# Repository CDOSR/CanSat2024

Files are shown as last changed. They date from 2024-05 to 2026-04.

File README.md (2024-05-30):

# CanSat2024

Welcome to the CanSat2024 project repository. This project is dedicated to the design, development, and deployment of a CanSat, a small satellite designed for educational purposes.

## Table of Contents
- [Introduction](#introduction)
- [Project Structure](#project-structure)
- [Getting Started](#getting-started)
- [Hardware](#hardware)
- [Software](#software)
- [Contributing](#contributing)
- [License](#license)

## Introduction
CanSat2024 is an educational initiative aimed at providing hands-on experience in satellite engineering. Participants will design, build, and launch a small satellite to achieve specific mission objectives.

## Project Structure
- `Documents/`: Documentation and guidelines for the project.
- `Hardware/`: Schematics, PCB designs, and hardware-related files.
- `Software/`: Source code for the CanSat's firmware and ground control software.

## Getting Started
### Prerequisites
- Basic understanding of electronics and programming.
- Required tools and components listed in `docs/tools_and_components.md`.

### Installation
1. Clone the repository:
    ```sh
    git clone https://github.com/CDOSR/CanSat2024.git
    ```
2. Navigate to the project directory:
    ```sh
    cd CanSat2024
    ```

## Hardware
Details about the hardware components, including sensors, microcontrollers, and power systems, can be found in the `hardware/` directory. Refer to `hardware/README.md` for more information.

## Software
The software for the CanSat includes firmware for onboard systems and software for ground control. Instructions for building and deploying the software are available in the `software/` directory. Refer to `software/README.md` for more details.

## Contributing
We welcome contributions from the community. Please read `CONTRIBUTING.md` for guidelines on how to contribute to the project.

## License
This project is licensed under the MIT License. See the `LICENSE` file for details.

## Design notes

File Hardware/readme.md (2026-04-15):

# Hardware

CAD sources for the custom PCBs designed for CanSat 2024.

## Contents

- `PCB Designs/` — Eagle `.sch` (schematic) and `.brd` (board layout) files
  for the four custom boards:
  - `Comm_board_2024_L76` — communications board with Quectel L76 GNSS
  - `Comm_board_2024_M8N` — communications board with u-blox NEO-M8N GNSS
  - `Power_board_2024` — power distribution and battery management
  - `Sensor_board_2024` — sensor aggregation (IMU, environmental, etc.)

## Component datasheets

Datasheets for the third-party components used on these boards live under
[`Documentation/Hardware/Data Sheets/`](../Documentation/Hardware/Data%20Sheets/)
— kept separate so this tree stays focused on our own CAD sources rather
than vendor reference material.

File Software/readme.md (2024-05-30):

# Software Directory

This directory contains all the software-related files for the CanSat2024 project.

## Contents
- `Main Can/`: Source code for the CanSat's onboard firmware.
- `Base Station/`: Software for the ground control station.

## Firmware
The `Main Can/` directory contains the source code that runs on the CanSat's microcontroller. This code is responsible for sensor data collection, communication, and control operations.

### Building the Firmware
To build the firmware, navigate to the `firmware/` directory and use the provided Makefile:
```sh
cd `Main Can`
make

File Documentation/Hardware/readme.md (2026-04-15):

# Hardware Documentation

Reference material for the CanSat 2024 hardware subsystems.

## Contents

- `Data Sheets/` — Manufacturer datasheets for every sensor, regulator,
  GNSS module, radio, and battery IC used on the custom boards.

## Related

The team's own hardware sources — Eagle `.sch` and `.brd` CAD files for
the four custom boards — live under [`Hardware/`](../../Hardware/) at
the repo root, so that vendor reference PDFs don't clutter the CAD tree.

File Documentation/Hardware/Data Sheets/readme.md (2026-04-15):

# Component Data Sheets

Manufacturer datasheets for the components used on the CanSat 2024
custom PCBs. One PDF per part, filename matches the manufacturer part
number.

| File | Part | Role |
|---|---|---|
| `AP2112M-3.3TRG1.pdf` | Diodes AP2112M-3.3 | 3.3 V LDO regulator |
| `BME280.pdf` | Bosch BME280 | Pressure / humidity / temperature |
| `BME688.pdf` | Bosch BME688 | Environmental + gas sensor |
| `ICM-20648.pdf` | TDK InvenSense ICM-20648 | 6-axis IMU |
| `L76-M33.pdf` | Quectel L76 | GNSS module |
| `LPS25HBTR.pdf` | ST LPS25H | MEMS pressure sensor |
| `MAX17048-MAX17049.pdf` | Maxim MAX17048/049 | Li-ion fuel gauge |
| `MCP73831T-2ACI_OT.pdf` | Microchip MCP73831 | Li-ion charger IC |
| `MCP9808-E_MS.pdf` | Microchip MCP9808 | Digital temperature sensor |
| `RN2483A-I_RM105.pdf` | Microchip RN2483 | LoRaWAN radio module |
| `VEML6075.pdf` | Vishay VEML6075 | UVA / UVB sensor |

The boards that use these parts — schematic and layout — live under
[`Hardware/PCB Designs/`](../../../Hardware/PCB%20Designs/) at the repo
root.

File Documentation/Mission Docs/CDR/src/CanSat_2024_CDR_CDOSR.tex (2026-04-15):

\documentclass[11pt]{article}
\usepackage{CDOSR_CanSat, lipsum, amssymb, array, hyperref}
\usepackage{pdflscape}
\cansatstyle
\graphicspath{{../../common/}{./}}

\title{Preliminary Design Report}
\author{Team: CDOSR (CoderDojo Space Robotics Oradea)}
\date{May 10, 2024}

\begin{document}

\cansattitle{Critical Design Report}{images/img_CDOSR.png}{images/img_CANSAT_RO.png}

\newpage

\tableofcontents
\pagestyle{plain}

\newpage
\input{section_0/section_0}
\input{section_1/section_1}
\input{section_2/section_2}
\input{section_3/section_3}
\input{section_4/section_4}
\input{section_5/section_5}
\input{section_6/section_6}
\input{section_7/section_7}

\theendnotes

\appendix
\newpage

\appendix
\addcontentsline{toc}{section}{Appendices}
\section*{Appendices}
% \section{Time Management - Gantt Chart}\label{A1}

\subsection{Task list}

\begin{enumerate}[]
    \item \textbf{Can Design and Manufacturing} - in progress
    \begin{itemize}
    \item Can design in 3D - In progress
        \begin{itemize}
            \item models for main IC
            \item power board
            \item sensor board
            \item can assembly model
        \end{itemize}
    \item Parts (Acquisition) - in progress
    \end{itemize}    
    \item \textbf{PCB Design and Manufacturing} - in progress
    \begin{itemize}
        \item PCB Design
        \begin{itemize}
            \item Power Board Design - in progress
            \item Sensor Board Design  - in progress
        \end{itemize}
        \item PCB Manufacturing
        \begin{itemize}
            \item Power Board - scheduled
            \item Sensor Board - scheduled
        \end{itemize}    
    \end{itemize}
    \item \textbf{Can Software}:
    \begin{itemize}
        \item {Mission Software}
        \begin{itemize}
            \item Sensor integration - scheduled
            \item TX/RX between devices - scheduled
            \item New mainboard software integration - scheduled
            \item Base station software - scheduled
        \end{itemize}
        \item {Post Mission Software}
        \begin{itemize}
            \item Data aggregation - scheduled
            \item Data analysis - scheduled
            \item Reporting - scheduled
        \end{itemize}
    \end{itemize}
    \item \textbf{Testing} - scheduled
    \begin{itemize}
        \item Recovery system
        \begin{itemize}
            \item Parachute - in progress, partly done
            \item Locator for Can - scheduled
        \end{itemize}
        \begin{itemize}
            \item Sensor reading - done
            \item Can-Base transmission - scheduled
            \item Base station - scheduled
        \end{itemize}
        \item Hardware
        \begin{itemize}
            \item Electronics - scheduled
            \item Batteries - scheduled
            \item Receiver Antenna - scheduled
        \end{itemize}
        \item Structure
        \begin{itemize}
            \item Crashproof - scheduled
        \end{itemize}
    \end{itemize}
\end{enumerate}

\section{Mission milestones}\label{A33}

These milestones have been designed to keep us on track and ensure that we successfully meet our project goals and deadlines.
\begin{itemize}[leftmargin=1cm, itemindent=0.25cm, noitemsep, topsep=0pt, label=$\bullet$]
    % \item Team Formation and Project Planning:
    % \begin{itemize}[label=\ding{111}, noitemsep, topsep=2pt]
    %     \item Establish team roles and responsibilities
    %     \item Recruit suitable team members for each role
    % \end{itemize}
    \item Define Project Scope and Objectives:
    \begin{itemize}[label=\ding{111}, noitemsep, topsep=0pt]
        \item Purpose of the project: to successfully detect muons and analyze the environment, light conditions
        \item Objectives to be achieved on launch day and post-launch analysis:
        \begin{multicols}{2}
        \setlength{\topsep}{0pt}
        \setlength{\partopsep}{0pt}
        \begin{itemize}[label=\ding{51}, noitemsep, topsep=0pt]
        \item Successful launch
        \item Live RF telemetry
        \item Successful parachute deployment
        \item All systems nominal (good sensor and location data)
        \item Descent rate between 7-10m/s
        \item Landing confirmation
        \item Recovery of the CanSat
        \item Generating reports
        \end{itemize}
        \end{multicols}
    \end{itemize}
    \item Develop a Detailed Project Plan and Timeline:
    \begin{itemize}[label=\ding{111}, noitemsep, topsep=0pt]
        \item Assign tasks related to social media promotion and sponsor search;
        \item Determine cooperation method (online/programs/meetings etc.)
    \end{itemize}
    \item Research and Design:
    \begin{itemize}[label=\ding{111}, noitemsep, topsep=0pt]
        \item Conduct research on required components and technologies for the mission;
        \item Design the payload's structure and select materials;
        \item Submit Preliminary Design Report;
        \item Develop a prototype and test sensors and electronics;
        \item Promote the project on social media platforms and begin searching for sponsors.
    \end{itemize}
    \item Integration and Testing:
    \begin{itemize}[label=\ding{111}, noitemsep, topsep=0pt]
        \item Integrate sensors and electronics into the payload's structure;
        \item Conduct testing and calibration;
        \item Ensure that the CanSat meets weight and size requirements;
    \end{itemize}
    \item Launch Preparation:
    \begin{itemize}[label=\ding{111}, noitemsep, topsep=0pt]
        \item Conduct pre-launch testing;
        \item Pre-launch checklist.
    \end{itemize}
    \item Primary and Secondary Missions:
    \begin{itemize}[label=\ding{111}, noitemsep, topsep=0pt]
        \item Verify that the payload met the primary mission requirements;
        \item Collect the missions data from the sensors;
        \item Conduct data analysis and report on the results;
        \item Share updates and photos of the data analysis on social media platforms.
    \end{itemize}
    \item Submit Design Reviews
    \begin{itemize}[label=\ding{111}, noitemsep, topsep=0pt]
        \item Preliminary Design Review;
        \item Critical Design Review.
    \end{itemize}
    \item Final Report and Presentation:
    \begin{itemize}[label=\ding{111}, noitemsep, topsep=0pt]
    \item Prepare a final report documenting the project's objectives, methods, and results;
    \item Develop a presentation to showcase the mission and its capabilities;
    \item Share the presentation on social media platforms to showcase the project's achievements and thank sponsors for their support.
    \end{itemize}
\end{itemize}

\newpage

% \section{Flight Simulations}\label{A33}

% % \begin{landscape}
% \begin{figure}[htbp]
%     \centering
%     \includegraphics[width=0.95\textwidth]{images/plot_rcrc.png}
%     \caption{\small{Flight simulation graphs}}
%     \label{fig:fins}
% \end{figure}
% % \end{landscape}

% \begin{table}[htbp]
% \centering
% \arrayrulecolor{DeepSkyBlue4}
% \begin{tabular}{|>{\columncolor{DeepSkyBlue4}}cc|}
% \hline
% \textbf{\color{white!50}{Velocity off rod}} & \cellcolor{LightCyan1!50}\(\SI{12.9}{\meter/\second}\)\\
% \textbf{\color{white!50}{Apogee}} & \(\SI{221}{\meter}\)\\
% \textbf{\color{white!50}\textbf{Velocity at deployment}} & \cellcolor{LightCyan1!50}\(\SI{6.03}{\meter/\second}\)\\
% \textbf{\color{white!50}\textbf{Max. velocity}} & \(\SI{62.2}{\meter/\second}\)\\
% \textbf{\color{white!50}\textbf{Max. acceleration}} & \cellcolor{LightCyan1!50}\(\SI{99.1}{\meter/\second^2}\)\\
% \textbf{\color{white!50}\textbf{Time to apogee}} & \(\SI{7.3}{\second}\)\\
% \textbf{\color{white!50}\textbf{Flight time}} & \cellcolor{LightCyan1!50}\(\SI{55.1}{\second}\)\\
% \textbf{\color{white!50}\textbf{Ground hit velocity}} & \(\SI{4.66}{\meter/\second}\)\\ 
% \hline
% \end{tabular}
% \caption{\small{Flight Simulation Information}}
% \end{table}

% \begin{wrapfigure}{l}{0.95\textheight}
%     \centering
%     \includegraphics[width=13.5cm]{images/Gantt.eps}
%     %\caption{\small{CDOSR Gantt Chart for CanSat 2023.}}
%     \label{fig:gantt}
% \end{wrapfigure}

% \begin{figure}[h]
%     \centering
%     \includegraphics[width=11.7cm]{images/Gantt.eps}
%     %\caption{\small{CDOSR Gantt Chart for CanSat 2023.}}
%     \label{fig:gantt}
% \end{figure}

% \begin{minipage}[c][\textheight]{\textwidth}
%     \vspace*{\fill}
%     \begin{figure}[h] % Use 'p' for a dedicated page for the figure
%     \centering
%     \includegraphics[width=\textwidth, keepaspectratio]{images/Gantt.eps}
%     %\caption{Your caption here}
%     \label{fig:gantt}
%     \end{figure}
%     \vspace*{\fill}
% \end{minipage}

\section{Dual parachute design (Payload's Case)}\label{A4}
\coloredbox{LightCyan1!50}{DeepSkyBlue4}{DeepSkyBlue4}{
    \begin{minipage}{0.4\textwidth}
    The smaller parachute had a diameter of 21.7 cm and a surface area of 370 cm$^{2}$, which is designed to slow down the descent speed to 9 meters per second. The design of this parachute was based on the principles of aerodynamics and is intended to withstand strong winds and turbulent weather conditions. We believe that this parachute will be instrumental in ensuring a safe and successful landing of our Payload during windy weather conditions.
    \end{minipage}
    \hfill
    \begin{minipage}{0.4\textwidth}
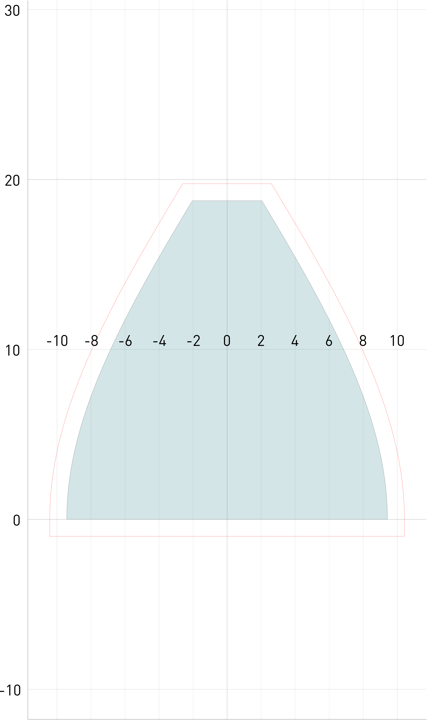
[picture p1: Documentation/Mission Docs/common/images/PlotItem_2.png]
    
    \end{minipage}
}
\coloredbox{LightCyan1!50}{DeepSkyBlue4}{DeepSkyBlue4}{
    \begin{minipage}{0.4\textwidth}
    The second parachute was designed for use during calm weather conditions and had a diameter of 32.6 cm and a surface area of 834 cm$^{2}$, which is designed to slow down the descent speed to 6 meters per second. This parachute was optimized for stable and predictable conditions and is intended to provide a gentle and controlled descent of the Payload during calm weather conditions.
    \end{minipage}
    \hfill
    \begin{minipage}{0.4\textwidth}
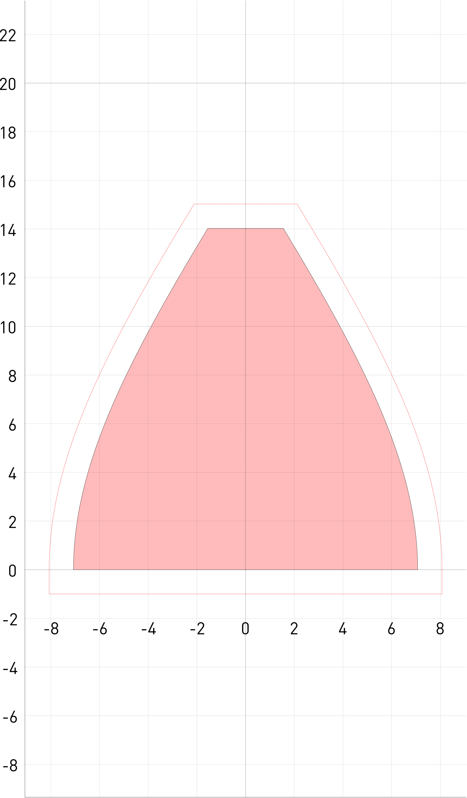
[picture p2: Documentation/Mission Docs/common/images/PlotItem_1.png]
    
    \end{minipage}
}
\newpage

\section{Payload  -  software design}\label{AE22}
\begin{figure}[htbp]
    \centering
    
    \caption{\small{Software diagram.}}
    \label{fig:codeblocks}
\end{figure}
\newpage

\section{Payload  - electrical design}\label{AE2}
% \begin{landscape}
\begin{figure}[h]
    \centering
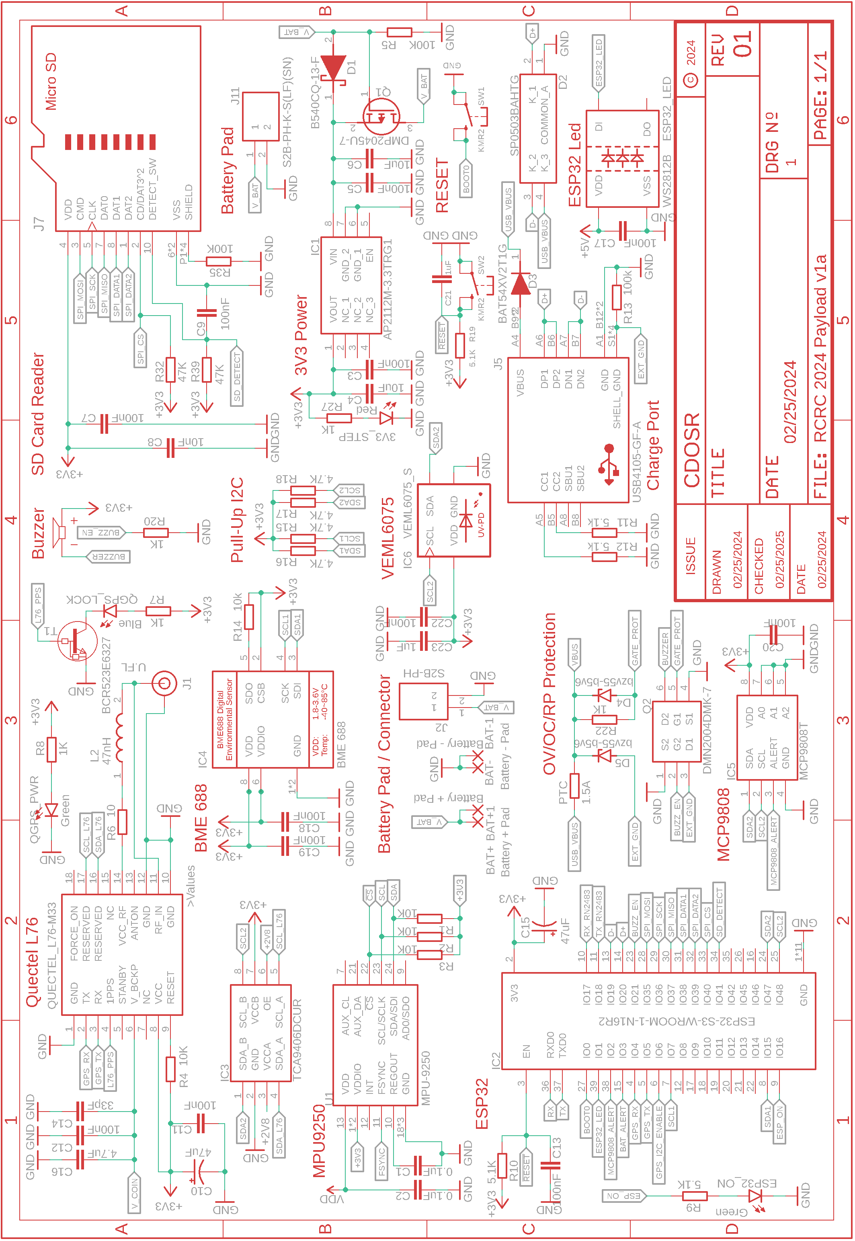
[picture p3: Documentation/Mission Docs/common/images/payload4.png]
    
    \caption{\small{CDOSR payload electrical scheme.}}
    \label{fig:gantt}
\end{figure}
% \end{landscape}
\newpage

\section{Base station - electrical design}\label{AEE2}

% \begin{landscape}
\begin{figure}[h]
    \centering
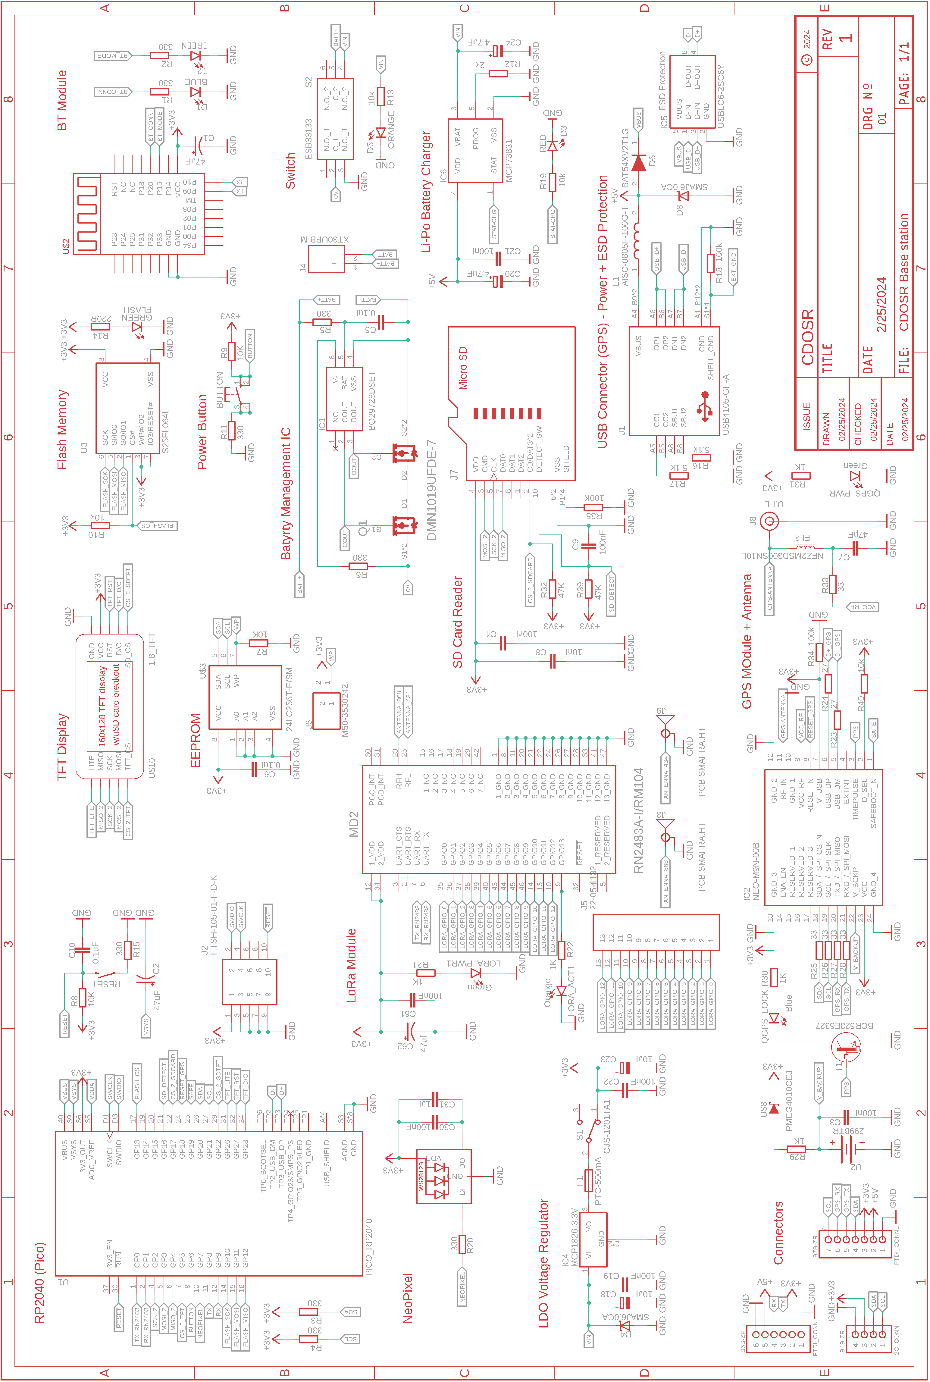
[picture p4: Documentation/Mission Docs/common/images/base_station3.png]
    
    \caption{\small{CDOSR base station electrical scheme.}}
    \label{fig:gantt}
\end{figure}
    
% \end{landscape}

\newpage

% \section{Time Management - Gantt Chart}\label{A2}

% \begin{figure}[h]
%     \centering
%     \includegraphics[width=15.5cm]{images/Gantt.eps}
%     \caption{\small{CDOSR Gantt Chart for RCRC 2024.}}
%     \label{fig:gantt}
% \end{figure}

\newpage

\section{Test plan}\label{A1}

\begin{itemize}[leftmargin=1cm, itemindent=0.25cm, noitemsep, topsep=0pt, label=\ding{51}]
\item Mission Objective Test
\begin{itemize}[label=\ding{111}, noitemsep, topsep=2pt]
\item Verify if the payload meets the competition mission requirements
\item Check that the sensors are functioning properly
\end{itemize}

\item Mechanical Test
\begin{itemize}[label=\ding{111}, noitemsep, topsep=2pt]
\item Make sure that the structure and enclosure are sturdy and can withstand launch and landing
\item Verify the parachute deployment and fixing are functional and reliable
\end{itemize}

\item Software Test
\begin{itemize}[label=\ding{111}, noitemsep, topsep=2pt]
\item Verify that the software is correctly installed and functional
\item Ensure that the software is properly processing data from the sensors and instruments
\end{itemize}

\item Communication Test
\begin{itemize}[label=\ding{111}, noitemsep, topsep=2pt]
\item Ensure that the payload can communicate with the ground station
\item Verify that telemetry data can be received and decoded correctly
\item Test the range and the reliability of the communication link
\end{itemize}

\item Power Test
\begin{itemize}[label=\ding{111}, noitemsep, topsep=2pt]
\item Verify that the power system meets the power budget and has sufficient power to operate the payload
\item Test the duration of the battery life and ensure that power consumption is minimized wherever possible
\end{itemize}

\item Integration Test
\begin{itemize}[label=\ding{111}, noitemsep, topsep=2pt]
\item Verify if all the components of the payload are properly integrated and functioning correctly
\item Test the overall functionality
\end{itemize}

\item Ground Station Test
\begin{itemize}[label=\ding{111}, noitemsep, topsep=2pt]
\item Verify that the antennas are properly installed and functional
\item Verify that the ground station software can display data from the payload
\end{itemize}

\item Battery Charging Test
\begin{itemize}[label=\ding{111}, noitemsep, topsep=2pt]
\item Test the battery charging system and verify that it can fully charge the batteries within a reasonable amount of time
\item Verify that the charging system is safe and reliable
\end{itemize}

\item Post-Mission Test
\begin{itemize}[label=\ding{111}, noitemsep, topsep=2pt]
\item Verify if the payload has returned all the required data
\item Check the data for accuracy and completeness
\item Analyze the data and compare it to the mission objectives
\end{itemize}

\end{itemize}

\section{Sensor testing}\label{A22}

\begin{itemize}[labelwidth=0cm, leftmargin=0cm, itemindent=0.7cm, noitemsep, topsep=0pt, label={}]
\item \textbf{Pressure sensor test}:
\begin{itemize}[labelwidth=2cm, leftmargin=1.9cm, label=\ding{109}, noitemsep, topsep=2pt]
\item[\faTasks] \textbf{Task}: Expose the used sensor to a pressure change and compare the results with a reference device.
\item[\faFlask] \textbf{Method}: Place the target and reference sensors in a sealed container with a known volume of air and measure the pressure change with a manometer or a barometer. The pressure can be changed by altering the volume of the container or by using a hand pump.
\item[{\faHourglass[3]}] \textbf{Estimated testing time duration}: 1-2 hours
\item[{\faCheckSquare}] \textbf{Acceptance criteria}: The test will be considered positive when both sensors show the same pressure without measuring errors.
\end{itemize}
\item \textbf{Temperature sensor test}:
\begin{itemize}[labelwidth=2cm, leftmargin=1.9cm, label=\ding{109}, noitemsep, topsep=2pt]
\item[\faTasks] \textbf{Task}:  Check whether the target device and the reference device show the same temperature within 24 hours 
\item[\faFlask] \textbf{Method}: Place both the target device and the reference device in the same location and monitor their temperature readings at regular intervals for 24 hours
\item[{\faHourglass[3]}] \textbf{Estimated testing time duration}:  24 hours
\item[{\faCheckSquare}] \textbf{Acceptance criteria}: The test will be considered positive when both sensors show the same temperature without significant deviation.
\end{itemize}
\item \textbf{Humidity sensor test}:
\begin{itemize}[labelwidth=2cm, leftmargin=1.9cm, label=\ding{109}, noitemsep, topsep=2pt]
\item[\faTasks] \textbf{Task}:  Place the target sensor and the reference device in a humidity chamber where the humidity will be increased or decreased to a specific level, and the readings will be compared.
\item[\faFlask] \textbf{Method}: The target sensor and the reference device will be placed in a humidity chamber where the humidity level will be gradually increased or decreased to a specific level. The readings from both sensors will be recorded and compared.
\item[{\faHourglass[3]}] \textbf{Estimated testing time duration}:  6 hours
\item[{\faCheckSquare}] \textbf{Acceptance criteria}: The test will be considered positive when both sensors show the same humidity level without significant deviation.
\end{itemize}
\item \textbf{UV sensor test}:
\begin{itemize}[labelwidth=2cm, leftmargin=1.9cm, label=\ding{109}, noitemsep, topsep=2pt]
\item[\faTasks] \textbf{Task}:  Expose the target sensor and the reference device to UV radiation from a UV light source and compare the readings.
\item[\faFlask] \textbf{Method}: The target sensor and the reference device will be exposed to UV radiation from a UV light source for a specific duration, and the readings will be recorded and compared.
\item[{\faHourglass[3]}] \textbf{Estimated testing time duration}:  1 hour
\item[{\faCheckSquare}] \textbf{Acceptance criteria}: The test will be considered positive when both sensors show the same UV index without significant deviation.
\end{itemize}
\item \textbf{GPS test}:
\begin{itemize}[labelwidth=2cm, leftmargin=1.9cm, label=\ding{109}, noitemsep, topsep=2pt]
\item[\faTasks] \textbf{Task}:  Test the accuracy of the GPS module by comparing the location obtained by the CanSat with the actual location.
\item[\faFlask] \textbf{Method}: The location data collected by the GPS module during this time will be recorded and compared to the actual location using a separate reference system. The reference system may be a ground-based GPS receiver or a separate device with accurate location data.
\item[{\faHourglass[3]}] \textbf{Estimated testing time duration}:  1 hour
\item[{\faCheckSquare}] \textbf{Acceptance criteria}: The test will be considered positive if the error margin is within an acceptable range.
\end{itemize}
\end{itemize}

\section{Mechanical stress testing}\label{A33333}

\begin{itemize}[labelwidth=0cm, leftmargin=0cm, itemindent=0.7cm, noitemsep, topsep=0pt, label={}]
\item \textbf{Drop resistance test}:
\begin{itemize}[labelwidth=2cm, leftmargin=1.9cm, label=\ding{109}, noitemsep, topsep=2pt]
\item[\faTasks] \textbf{Task}: Conduct a crash test to ensure the payload components can withstand the impact of a fall.
\item[\faFlask] \textbf{Method}: Prototypes will be dropped from a tower or drone to achieve the required descent speed. A fall test without a parachute will also be performed. Optionally, a 3-axis accelerometer will be added to record any G-force during the test.
\item[{\faHourglass[3]}] \textbf{Estimated testing time duration}: Estimated to be a few hours.
\item[{\faCheckSquare}] \textbf{Acceptance criteria}: All components should remain intact, and the electronics should continue to work continuously.
\end{itemize}
\item \textbf{Long-term G-force tests}:
\begin{itemize}[labelwidth=2cm, leftmargin=1.9cm, label=\ding{109}, noitemsep, topsep=2pt]
\item[\faTasks] \textbf{Task}: Simulate the G-forces that may occur during rocket transport to test the CanSat components' endurance.
\item[\faFlask] \textbf{Method}: The payload model will be placed on a carousel or string and rapidly rotated to generate the required overload due to the centrifugal force.
\item[{\faHourglass[3]}] \textbf{Estimated testing time duration}: The test will last for several hours.
\item[{\faCheckSquare}] \textbf{Acceptance criteria}: All components should remain intact, and the electronics should continue to work continuously throughout the test period.
\end{itemize}
\end{itemize}

\end{document}

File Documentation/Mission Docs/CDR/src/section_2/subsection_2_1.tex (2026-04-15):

\subsection{Mission Overview}

The CoderDojo Space Robotics project team will execute the mission by designing and constructing a CanSat that will launch and deploy from an altitude of approximately 1000 meters. During the CanSat's descent, it must maintain a speed between 5 and 10 meters per second, while it simultaneously collects and transmits key environmental data. This data will include temperature, pressure, spatial positioning, and UV radiation levels. In addition to these, the CanSat is uniquely equipped to detect muons. All of this data will be transmitted in real-time to the ground station and stored onboard. After landing, the CanSat will signal its coordinates using a buzzer, activating the recovery system.

These key elements will play an essential role in accomplishing the mission objectives. Here is a brief explanation of each element:
\begin{itemize}[leftmargin=1.27cm, itemindent=0cm, topsep=2pt, label=\faTasks]
    \item[\faThermometerQuarter] \textbf{Sensor System}: A sensor system is critical to the mission's success as it helps to measure various parameters that are important for the experiment. The sensor system can measure parameters such as temperature, pressure, inertial performance, UV, and light intensity. These measurements will provide valuable data for the post-launch data analysis.
    \coloredbox{LightCyan1!50}{DeepSkyBlue4}{DeepSkyBlue4}{
        {During the descent, the CanSat will record, store, and transmit the following data:
        \begin{multicols}{2}[\vspace{-0.6\baselineskip}]
            \begin{itemize}[noitemsep, topsep=0pt, label=\ding{111}]
                \item Humidity and air temperature
                \item Barometric pressure
                \item GPS Location
                \item Magnetic field
                \item Orientation
                \item Position in space using a gyroscope
                \item UV Index
            \end{itemize}
        \end{multicols}
        \vspace*{-0.75\baselineskip}
        }
    }
    \item[\faMicrochip] \textbf{Microcontroller}: The microcontroller is responsible for controlling the various subsystems of the CanSat. It provides a reliable and efficient way to control the CanSat's functions, making it a crucial part of the overall system.
    \item[\faBroadcastTower] \textbf{Telemetry Syste}m: The telemetry system is responsible for sending data back to the ground station. It uses GSM and RF modules to transmit data, which can be analyzed in real time by the mission team. This system helps to ensure that the mission objectives are met and that the data collected is of high quality.
    \item[ \faParachuteBox] \textbf{Recovery System}: The recovery system is essential to ensure the CanSat is safely returned to the ground. It consists of audible alarms that alert the ground station to the CanSat's location. This system will help to prevent damage to the CanSat and ensure that the data collected during the mission is preserved.
    \item[\faChartBar] \textbf{Post-Launch Data Analysis}: Post-launch data analysis is essential for interpreting the data collected during the mission. It allows the mission team to evaluate the success of the mission and determine whether the mission objectives were met. This analysis can help to inform future missions and experiments. 
\end{itemize}

%\begin{figure}[htbp]
%  \centering
%  \includesvg{img_Block_Diagram_2023.svg}
%  \caption{svg image}
%\end{figure}

\begin{figure}[htbp]
\centering
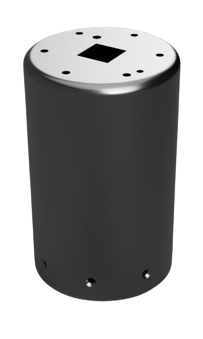
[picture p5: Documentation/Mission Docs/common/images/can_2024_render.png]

\caption{\small{Base block diagram for the CanSat and the ground station.}}
\label{fig:bloc_diagrame}
\end{figure}

Several onboard devices will make the mission possible, the key ones being:
    \begin{multicols}{2}[\vspace{-0.5\baselineskip}]
        \begin{itemize}[leftmargin=1.75cm,itemindent=0cm, noitemsep, topsep=2pt, label=\faCheck]
            \item[\faMicrochip] MicroController (ESP32 Wroom or Raspberry Py PR2040)
            % \item[\faCamera] Cameras (ESP32 With Camera Module OV2640)
            \item[ \faWifi] Data transceiver (LoRa)
            \item[\faThermometerQuarter] Humidity and temperature sensors %(BME 688, MCP 9808)
            \item[\faMapMarked] GPS (L76GNSS)
            \item[\faCompass] Navigation sensor %(LSM6DS33 gyroscope \& LIS3MDL compass )
            \item[\faBatteryHalf] High-performance batteries
            \item[\faRadiation] SiPM (Silicon photomultiplier) detector for muons
            \item[\newaltitudeicon] Altimeter %(LPS25H)
            % \item[\newgsmicon] GSM module (SIM800L)
        \end{itemize}
        \vspace*{-0.75\baselineskip}
    \end{multicols}

% \sout{The ESP32 and Arduino Nano 33 BLE Sense boards are designed to collect data from various sensors during the flight, including location, temperature, and pressure. This data is stored on an SD card for later analysis, but it is also transmitted to the base station in real-time using the LoRa protocol.

% In addition to collecting data from sensors, the boards also receive data from two GPS modules. This data is routed to the GSM communication module, which sends the GPS coordinates of the CanSat to the base station. This allows the mission team to track the CanSat's location and monitor its progress during the flight.

% Overall, the combination of the ESP32 and Arduino Nano 33 BLE Sense boards provides a reliable and efficient way to collect and transmit data during the CanSat's flight. The data collected can be analyzed after the mission to gain insights into various environmental factors and improve future missions.}

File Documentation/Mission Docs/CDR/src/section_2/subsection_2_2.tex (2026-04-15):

\subsection{Mechanical/structural design}

For the mechanical design, several factors have been considered to ensure the payload's robustness and easy maintenance:
% \begin{itemize}[leftmargin=1.75cm,itemindent=0cm, noitemsep, topsep=3pt,  label=\faCheck]
%     \item \textbf{Component protection}: The payload's structure has been designed to protect the components from any external impact or shock during the launch and landing;
%     \item \textbf{Resilient structure}: The payload's structure includes shock-absorbing systems such as foam or gel-based layers, springs, or a combination of both. These systems will help to reduce the impact force during landing, preventing damage to the payload and its components;
%     \item \textbf{Easy removal of batteries and radio transmitters}: The batteries and radio transmitters are positioned in a way that allows for easy removal in case of any malfunction or for recharging and testing purposes.;
%     \item \textbf{Easy access to components}: The payload's body has been designed to allow easy extraction of the components for maintenance or replacement in case of malfunctions
%     \item \textbf{Easy removal of batteries and radio transmitter}s: The batteries and radio transmitters are positioned in a way that allows for easy removal in case of any malfunction or for recharging and testing purposes.
% \end{itemize}

\begin{itemize}
    \item \textbf{Component Protection}: The payload's structure will be designed to protect the components from any external impact or shock during the launch and landing.
    \item \textbf{Resilient Structure}: The payload's structure will include some shock-absorbing systems to reduce the impact force during landing, thereby preventing damage to the payload and its components.
    \item \textbf{Easy Removal of Batteries and Radio Transmitters}: The batteries and radio transmitters will be positioned in a way that allows for easy removal in the event of any malfunction, or for recharging and testing purposes.
    \item \textbf{Easy Access to Components}: The design of the payload's body will facilitate easy extraction of the components for maintenance or replacement in case of malfunctions.
\end{itemize}

By considering these factors, the team aims to create a robust and reliable payload capable of withstanding the mission's harsh conditions and delivering accurate data.

The payload's structure uses a combination of Polylactic Acid (PLA) and Acrylonitrile Butadiene Styrene (ABS). These lightweight 3D printing materials provide strength, durability, and exceptional design flexibility. This composition allows the can to endure the stresses of launch and landing while maintaining an aerodynamic shape. Additionally, the can is designed with a removable bottom or top section, facilitating easy access to its internal components for maintenance and repair without dismantling the entire structure.

The design ensures durability during launch and landing, distributing and absorbing high levels of stress and force. The aerodynamic design minimizes air resistance, helping achieve maximum altitude during launch.

\begin{figure}[htbp]
\centering

\caption{\small{Payload can with parachute cords attchement places.}}
\label{figmodule_diagrame}
\end{figure}

\begin{table}[htbp]
\centering
\arrayrulecolor{DeepSkyBlue4} % set color of vertical lines
\begin{tabular}{>{\centering\arraybackslash}m{1cm}>{\centering\arraybackslash}lc}
\hline
\rowcolor{DeepSkyBlue4}
&\textbf{\color{white!50}{CanSat Characteristics (description)}} & \textbf{\color{white}{Figure (units)}} \\
\hline
%\rowcolors{2}{LightCyan!50}{}
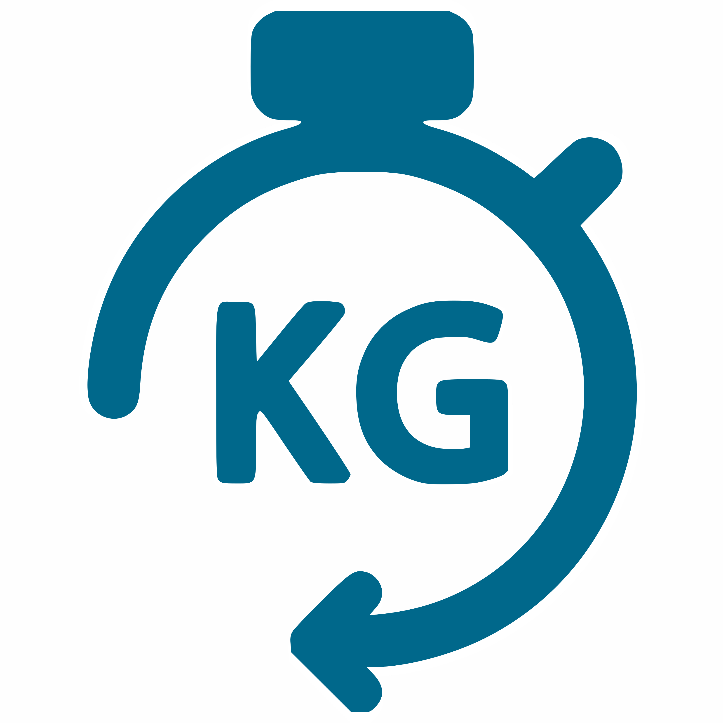
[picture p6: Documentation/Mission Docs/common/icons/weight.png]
\adjustbox{valign=m}{} & Total weight of the payload & 300 g \\
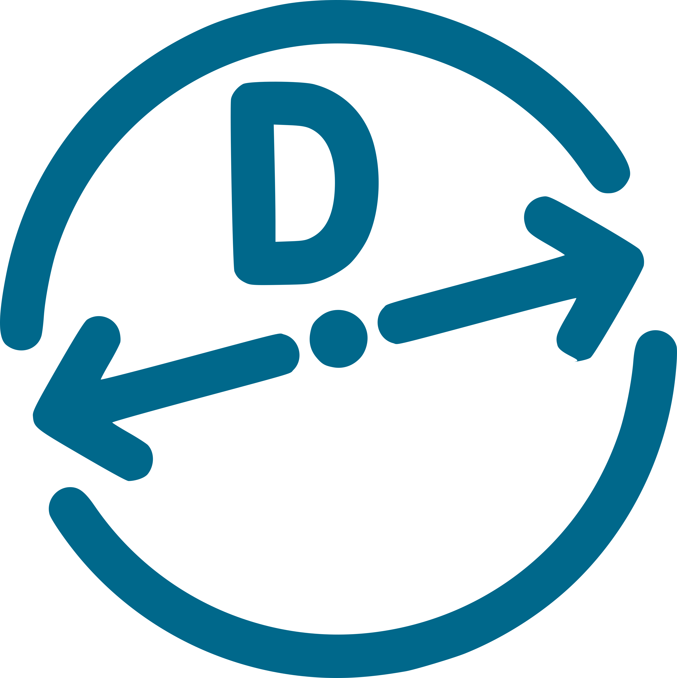
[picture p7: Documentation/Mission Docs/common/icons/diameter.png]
\rowcolor{LightCyan1!50}\adjustbox{valign=m}{} & Diameter of the payload & 66 mm\\
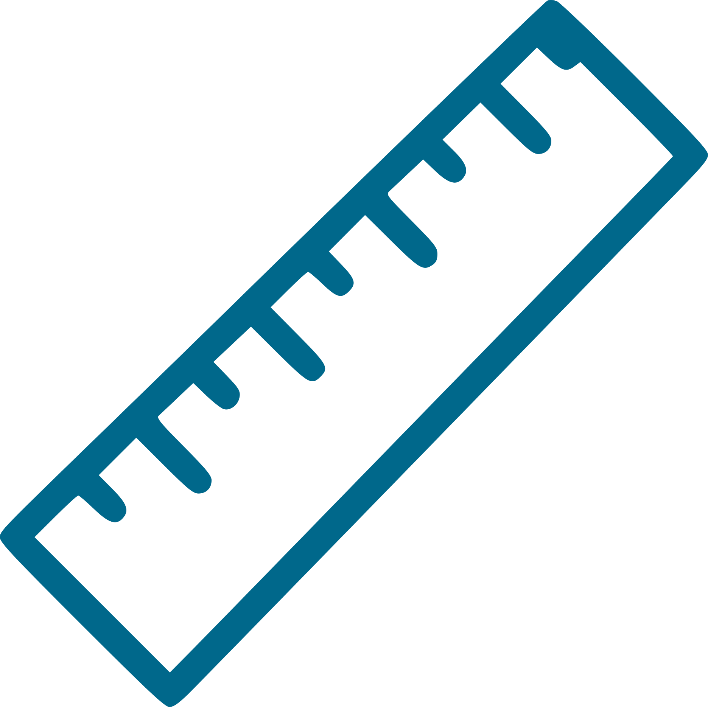
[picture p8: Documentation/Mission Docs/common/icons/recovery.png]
\adjustbox{valign=m}{} & Length of the recovery system,
including parachute & Max. 60 cm\\
\rowcolor{LightCyan1!50}
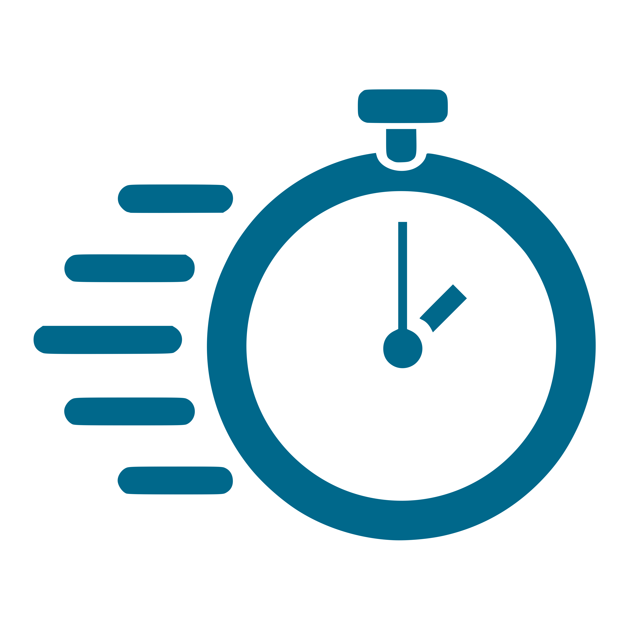
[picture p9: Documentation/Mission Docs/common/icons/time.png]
\adjustbox{valign=m}{} & Flight time scheduled & 120 s \\
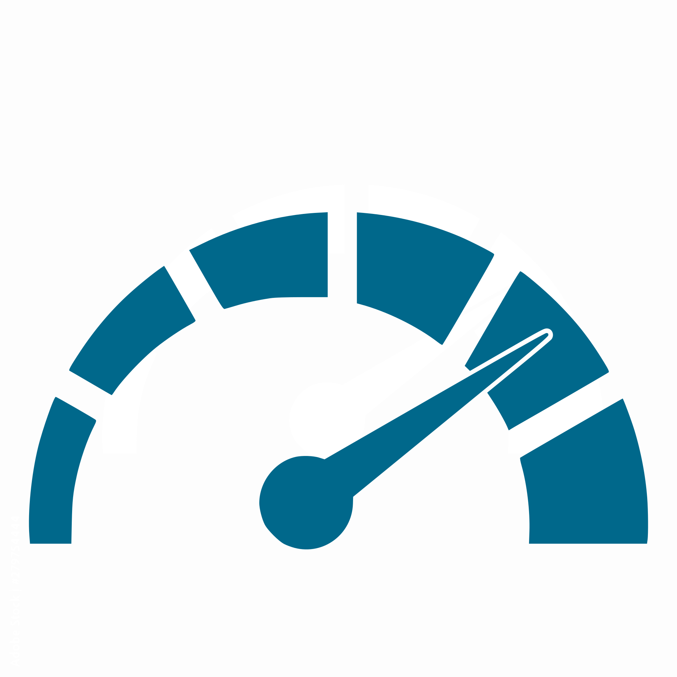
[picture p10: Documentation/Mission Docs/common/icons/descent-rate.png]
\adjustbox{valign=m}{} & Calculated descent rate of the payload & \SI{8}{\meter\per\second} \\
\rowcolor{LightCyan1!50}
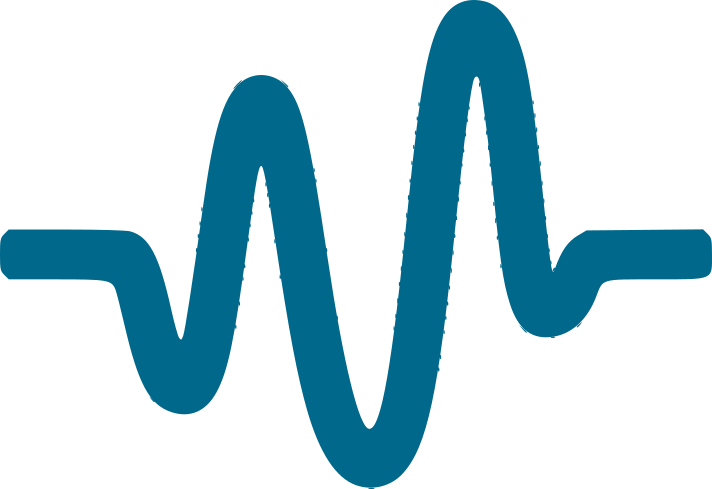
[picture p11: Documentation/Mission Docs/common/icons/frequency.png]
\adjustbox{valign=m}{} & Radiofrequency used for
communication & 868 MHz (LoRa) \\
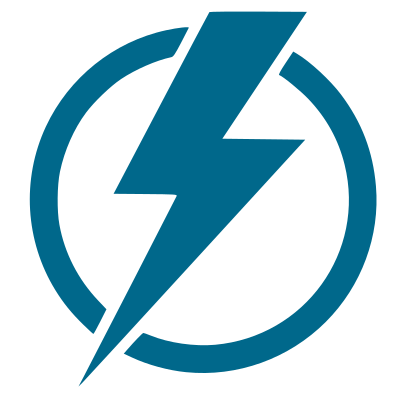
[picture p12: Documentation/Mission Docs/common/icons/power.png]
\adjustbox{valign=m}{} & Power consumption of the payload & 450 mA \\
\hline
\end{tabular}
\caption{\small{Main features of the CanSat}}
\end{table}

The payload is composed of several major components, including a few PCB boards that house all the necessary modules. The battery pack, which is the largest and heaviest component, is located at the bottom of the payload and contains one or two 18650 battery modules placed in a horizontal position (one battery) or vertical position (for two batteries). The upper part of the can houses the PCB layers, interconnected with mezzanine connectors, which are fixed in place using screws and glue. % Despite the relatively heavy weight of the battery pack, the can is designed to withstand the stress of launch and landing, and the components are secured in place with 3D-printed supports and foam to prevent damage.

% In order to ensure the functionality of the rocket payload's system during multiple tests, mechanical solutions were explored to protect the can and its contents from the impact of landing. After analyzing various options for shock-absorbing systems, we settled on prototyping and testing the most promising ideas based on their effectiveness, feasibility, and cost. Three potential concepts were identified, including:
% \begin{itemize}[leftmargin=1cm,itemindent=0.5cm, noitemsep, topsep=0pt, label=$\bullet$]
%     \item a foam or gel-based system;
%     \item a spring-based system;
%     \item a combined system using both foam or gel materials and springs.
% \end{itemize}

% The foam or gel-based system involves placing a layer of shock-absorbing foam or gel between two layers of the can, positioned at the bottom opposite to where the parachute is fastened. The spring-based system used a set of springs placed between two bottom layers of the can to compress and absorb the impact of the landing. Finally, the combined system used both springs and foam or gel materials to absorb the initial impact and further reduce the force of the landing, ultimately protecting the CanSat from damage.

The case of the payload will be fitted with inserts on the interior to reinforce its structural strength. To ensure secure closure, the lid is designed to be fastened tightly with screws that fit into specific holes in the cap, requiring a screwdriver to open it. Moreover, the case will have strategically positioned holes to facilitate ideal camera placement and ensure adequate airflow within the can.

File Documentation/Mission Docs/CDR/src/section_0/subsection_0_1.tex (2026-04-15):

\subsection{New progress statement for the team profile}

\subsubsection*{CanSat Developement}
\addcontentsline{toc}{subsubsection}{CanSat Developement}

\paragraph*{Mechanical design}
During our design phase, we've been evaluating two distinct can models using Autodesk Fusion. The initial model incorporates a lid positioned at the can's base, showcasing reliability and efficiency, albeit with certain constraints. The primary benefit of this bottom-lid configuration is its straightforward access to the can's interior, facilitating assembly and upkeep. Nevertheless, a drawback is the necessity for a swivel mechanism to attach the parachute, introducing additional weight and complexity. Moreover, this design complicates the rapid exchange of parachutes, potentially causing delays in practical scenarios.

Conversely, our second prototype features a lid on the can's top, streamlining the parachute's replacement without the swivel, thereby lightening the load and simplifying the design. This top-lid approach enhances access and maintenance ease. However, it presents a challenge in assembly, requiring components to be fitted through the upper opening.

\paragraph*{Electrical design}
In late January, our team initiated the development of the payload, opting to use Python for programming, with a choice between ESP32 or Raspberry Pi RP2040 as the hardware platform. After thorough research and comparison of both options, we settled on the ESP32 for its superior features.

Initially, the Raspberry Pi 2040 (Pico) was considered, but it ultimately failed to meet our requirements for connectivity interfaces.

Recently, we embarked on a project focused on integrating two ESP32 microcontrollers. We chose the ESP32 for its enhanced computational power and wireless functionality, aiming to develop a powerful and flexible system that aligns with our project goals.

\begin{table}[htbp]
\centering
\arrayrulecolor{DeepSkyBlue4} % set color of vertical lines
\begin{tabular}{>{\centering\arraybackslash}m{4cm}>{\centering\arraybackslash}llll}
\hline
\rowcolor{DeepSkyBlue4}
\textbf{\color{white!50}{Module}} & \textbf{\color{white}{Sensor}} & \textbf{\color{white}{I2C Bus}} & \textbf{\color{white}{I2C Address}} & \textbf{\color{white}{Manufacturer}} \\
Altimeter & LPS25H & 1 & 0xB8 &  STMicroelectronics \\
IMU & MPU-9250 & 2 & 0x68 - 0x69 & TDK InvenSense \\
Environmental Sensor & BME688 & 2 & 0x76 - 0x77 & Bosch \\
Temperature Sensor & MCP9808 & 1 & 0x18 & Microchip Technology \\
Ambient Light Sensor & VEML6075 & 1 & 0x10 & Vishay Semiconductors \\
GNSS / GPS Module & Quectel L76 & 2 & 0x20 - 0x21 & Quectel \\
\end{tabular}
\caption{Sensor modules with their respective I2C addresses and manufacturers}

\end{table}
\label{tab:sensors}

To gather the required components, we began sourcing them from suppliers like Mouser and TME.

\paragraph*{Recovery System}
For our team's inaugural payload deployment, we opted for a parachute with a hemispherical shape. However, we ultimately chose a hexagonal model for our recovery parachute.

In an effort to refine our parachute design, we experimented with a hexagonal parachute variant that more closely resembled the hemispherical model. To inform our design process, we utilized resources found online, such as \href{https://www.nakka-rocketry.net/paracon.html}{Nakka-Rocketry.net}, to construct a parachute model and develop a new test board equipped with additional IMU and communication modules. These enhancements enabled us to achieve a descent velocity of 6 to 9 meters per second, marking a successful adaptation.

As we prepared for our next mission, it became evident that new parachutes were necessary. The parachutes from previous missions were showing signs of wear and tear, posing a risk to the mission's success.

To address this, we began crafting prototype parachutes while awaiting delivery of essential materials from a German supplier. We selected Nylon Ripoff Cordura fabric for its 50 grams per square meter weight, procured from \href{https://www.extremtextil.de/}{extremtextil.de}, due to its renowned durability and high resistance to abrasion. This choice was pivotal in ensuring the parachute's performance and longevity in challenging conditions, contributing to a robust mission strategy.

During our test phase, we developed and tested two parachute designs, each optimized for different weather conditions: one smaller for windy environments and another for calm conditions. This approach ensures our readiness for various atmospheric scenarios. Detailed diagrams of these parachutes are available for review in the Annexes \ref{A4}.

\paragraph*{Ground Support Equipment}

As our team gets ready for the next flight, we realized how important it is to have a reliable and effective base station to keep track of our payload. To make sure our base station would work, we used two different plans.

Our first step was to find a new use for our old base station, which uses LoPy technology from Pycom. The members of our team had used this system before on other flights (CanSat), and it had proven to be very reliable and effective. We were sure that using this tried-and-true platform would give us a strong base station system and a backup plan in case we ran into any problems.

As our second step, we started making a new base station based on the Raspberry Pi. This change was made because we wanted to use and try new technological solutions in order to build a more advanced and flexible system that could meet the growing needs of our project. This also fit with our decision to use the ESP32 for the payload, which led us to try out the Pico as well. We chose the Raspberry Pico because it has better processing power, more connectivity choices, and more flexibility, all of which we thought were important for achieving our mission goals.

\subsubsection*{Sensor testing}
\addcontentsline{toc}{subsubsection}{Sensor testing}
Our team has advanced in the development and testing of the payload and individual sensors. We've performed targeted tests on acquired sensors, including for pressure, temperature, humidity, UV, and GPS functionalities.
\begin{itemize}
    \item \textbf{Pressure Sensor:} We validated this sensor by comparing its pressure readings under varying conditions with a reference sensor, ensuring accuracy (we exposed the used sensor to a pressure change and compared the results with a reference device. We placed both sensors in a sealed container with a known volume of air and measured the pressure change with a manometer or a barometer). The test was considered positive when both sensors showed the same pressure without measuring errors.

    \item \textbf{Temperature Sensor:} This sensor underwent a 24-hour test to confirm its temperature readings matched those of a reference sensor, verifying its reliability (we placed both sensors in the same location and monitored their temperature readings at regular intervals for 24 hours). The test was considered positive when both sensors showed the same temperature without significant deviation.

    \item \textbf{Humidity Sensor:} We assessed this sensor in a controlled humidity environment, comparing its readings to a reference to ensure precision (we placed the target sensor and the reference device in a humidity chamber where the humidity was increased or decreased to a specific level, and the readings were compared). The test was considered positive when both sensors showed the same humidity level without significant deviation.

    \item \textbf{UV Sensor:} We exposed this sensor to UV light, comparing its UV index readings with a reference sensor to confirm its effectiveness. The test was considered positive when both sensors showed the same UV index without significant deviation.

    \item \textbf{GPS Test:} The GPS module's location accuracy was verified by comparing its data with a known location, ensuring its precision for mission requirements. We recorded the location data collected by the GPS module during this time and compared it to the actual location using a separate reference system.  
\end{itemize}

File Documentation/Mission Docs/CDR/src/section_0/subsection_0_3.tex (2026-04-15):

\subsection{Detailed project status}

Our team is thrilled to share that we've made big steps forward in the building of our payload. The prototyping process has begun, which allows us to thoroughly test how each sensor works. Also, we've made different payload case designs to test how durable they are, and all of them have done great under tough conditions. Now that we have chosen the key parts and materials, our attention turns to putting them together in the best way possible so that the payload design exceeds other designs. As we move forward, we highlight how important it is to keep testing and making changes. The final PCB assembly and testing phase is scheduled for the coming weeks, which will ensure that the payload's electronics work at their best.

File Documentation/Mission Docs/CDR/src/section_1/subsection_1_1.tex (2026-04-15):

\subsection{Purpose of the mission}

Our CanSat mission aims to integrate multiple sensors for atmospheric and motion analysis, investigating cosmic ray interaction with the atmosphere into one small module. The sensors will measure pressure, temperature, humidity, UV intensity, CO/CO2 levels, and detect muons. By deploying diverse sensors on our small CanSat, we can address important topics, such as environmental degradation, air quality, and high-energy physics, while also our knowledge about satellite technology and climate issues, physics and a broad range of other sciences. Our goal is to foster curiosity of our world, while also providing insights for both the scientific community and our team.

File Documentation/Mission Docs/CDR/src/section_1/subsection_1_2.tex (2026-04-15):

\subsection{Team organisation and roles}

\subsubsection{Team name}
The team name CDOSR stands for Coderdojo Oradea Space Robotics. Coder Dojo is a community programming club that offers free, volunteer-led coding sessions for youth aged 7 to 17 to foster programming skills. CDOSR is a division within CoderDojo which is based in Oradea and is comprised of passionate rocketry enthusiasts. 

\subsubsection{Team composition}

The Space Robotics team of CoderDojo Oradea consists of a team leader and five members who are all between the ages of 15 and 18. Although they attend different high schools from Oradea, they are all members of the CoderDojo Oradea community. 

Each team member has a primary role that they diligently fulfill and secondary roles that can be a place to learn from other memebers, promoting equality and providing a pleaseant enviroment for everyone.
\vspace{1cm}
\begin{itemize}
    %\input{section_1/team_members/Daniel_Erzse}
    \input{section_1/team_members/Andrei_Tigan}
    \input{section_1/team_members/David_Chereches}
    \input{section_1/team_members/Daria_Fologea}
    \input{section_1/team_members/Alin_Lupau}
    \input{section_1/team_members/Andrei_Costea}
    \input{section_1/team_members/Mark_Trefi}
\end{itemize}

\subsubsection{Team's Activity:} 

The team has developed a 6-point action plan to ensure effective progression in the CanSat and its payload (CanSat) design and development process, including:
\begin{enumerate}[topsep=3pt]
    \item Effectively work together on the project by using the skills and knowledge of each team member and giving each person clear jobs and responsibilities based on their interests and skills;
    % \begin{itemize}[leftmargin=0.25cm,itemindent=0.5cm, noitemsep, topsep=2pt, label=\textbullet]
    %     \item Identify the strengths and areas of expertise of each team member.
    %     \item Create a team environment that values input and feedback from all members.
    %     \item Allocate roles and responsibilities based on these strengths and interests.
    %     \item Ensure each team member has a clear understanding of their role and responsibility in the project.
    % \end{itemize}
    \item Establish a clear plan and timeline for the design, development, and testing phases of the CanSat;
    % \begin{itemize}[leftmargin=0.25cm,itemindent=0.5cm, noitemsep, topsep=2pt, label=\textbullet]
    %     \item Develop a detailed plan outlining specific milestones, deadlines, and deliverables for each phase of the project.
    %     \item Regularly review and update the plan to ensure it remains on track and adaptable to any changes or challenges that may arise.
    % \end{itemize}
    \item Regularly communicate and meet to discuss progress, challenges, and potential solutions:
    % \begin{itemize}[leftmargin=0.25cm,itemindent=0.5cm, noitemsep, topsep=2pt, label=\textbullet]
    %     \item Schedule regular team meetings to discuss progress and challenges.
    %     \item Provide updates on individual tasks and responsibilities to ensure the team is working efficiently and effectively.
    %     \item Encourage open communication and idea-sharing to facilitate collaboration and problem-solving.
    % \end{itemize}
    \item Leverage a multitude of resources, particularly those available online, to bolster the team's advancement and growth;
    % \begin{itemize}[leftmargin=0.25cm,itemindent=0.5cm, noitemsep, topsep=2pt, label=\textbullet]
    %     \item Actively seek out and employ a variety of online resources and tools that aid in the design and development stages of the project.
    %     \item Keep up to date with relevant news, updates, and industry trends to enhance the team's knowledge and expertise.
    % \end{itemize}
    \item Continuously test and evaluate the CanSat design to ensure it meets competition requirements and performs as expected;
    % \begin{itemize}[leftmargin=0.25cm,itemindent=0.5cm, noitemsep, topsep=2pt, label=\textbullet]
    %     \item Develop a testing plan to ensure the CanSat design meets competition requirements and functions as expected.
    %     \item Regularly evaluate the design to identify areas for improvement and potential issues.
    %     \item Continuously iterate and improve the design based on feedback and testing results.
    % \end{itemize}
    \item Seek feedback and input from mentors and advisors to enhance the design and development process.
    % \begin{itemize}[leftmargin=0.25cm,itemindent=0.5cm, noitemsep, topsep=2pt, label=\textbullet]
    %     \item Regularly seek feedback and input from mentors and advisors to enhance the design and development process.
    %     \item Utilize feedback and input to improve the design and development process and enhance the team's knowledge and expertise.
    % \end{itemize}
\end{enumerate}

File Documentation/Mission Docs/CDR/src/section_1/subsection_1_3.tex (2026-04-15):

\subsection{Mission objectives}

{\textit{“Exploring the cosmos is not just about reaching for the stars; it's about inspiring the dreams of those who will one day touch them.” - Unknown}}
\vspace{0.5cm}

The mission objective for the CDOSR team is to conduct a detailed atmospheric analysis at an altitude of approximately 200 meters, primarily focusing on collecting atmospheric pressure, temperature data, and flight dynamics data using an Inertial Measurement Unit (IMU). This mission is designed to lay the groundwork for future, more extensive exploratory initiatives. In its primary role, the CanSat will meticulously record and transmit vital atmospheric data, including pressure and temperature, alongside critical IMU data capturing the acceleration and gyroscope readings, essential for understanding the CanSat's behavior during flight.

In addition to these main goals, the CanSat also has a very broad secondary mission. This involves measuring other environmental factors like humidity, UV light strength, carbon monoxide/dioxide. Furthermore, this mission takes an innovative step into cosmic research by detecting muons, enhancing our exploration of space's mysteries.

\subsubsection{Missions description}

The CanSat's \textbf{primary mission}, following its release and during its descent, is to measure air \textbf{temperature} and air \textbf{pressure}. It will transmit this data to the ground station at least once every second. The data collected will be analyzed using the barometric formula to determine the CanSat's altitude.

The secondary mission of the CDOSR team ambitiously expands on its primary goals by incorporating the measurement of diverse environmental parameters. This includes humidity, UV light intensity, carbon dioxide levels, and cosmic particle detection, alongside the core telemetry data. The mission comprises several key tasks:
\begin{itemize}[leftmargin=1.27cm, itemindent=0cm, topsep=2pt, label=\faTasks]
    \item {\textbf{Enhanced Atmospheric Analysis:}} Our CanSat will meticulously record atmospheric data at varying altitudes, focusing on temperature, humidity, and pressure. The aim is to construct a detailed atmospheric profile, providing valuable insights into atmospheric science and climatology.
    \item {\textbf{UV Light Intensity Monitoring:}} The CanSat will detect and record the amount of UV radiation at different altitudes during its descent. This data will be used to create a profile of the UV radiation intensity along the descending path. This information will help identify areas with high levels of UV radiation and raise awareness of the risks of skin damage and other health problems.
    \item {\textbf{Advanced Cosmic Particle Research:}} Delving into the field of high-energy physics, the CanSat is set to detect and study muons. This endeavor will not only enhance our knowledge of cosmic rays but also deepen our insight into the fundamental processes of space.
    \item {\textbf{Air Quality Assessment:}} The mission includes a thorough analysis of air quality, measuring carbon monoxide and other pollutants at various altitudes. This data will be instrumental in identifying pollution sources and aiding environmental policy-making concerning air quality.
\end{itemize}

\subsubsection{Measurements, investigations and tests}
Our mission emphasizes environmental monitoring by continuously tracking UV light intensity and carbon monoxide/dioxide levels throughout the CanSat's flight. This includes data collection and understanding the implications of these environmental factors at different altitudes. Our mission software is tailored for analysis, converting raw data into meaningful insights using graphical representations, detailed tables, and focused numerical analysis, providing an "X-ray" of the atmosphere.

A core objective of our mission is to detect muons with our CanSat. Muons are heavy elementary particles created when cosmic rays collide with gases in the Earth's upper atmosphere. Despite their short average lifespan of 2.2 microseconds, muons travel through the atmosphere, losing energy as they interact with various elements. This phenomenon, used in fields like Egyptology to discover hidden rooms in pyramids, is a fascinating subject of study. Although theory suggests that only about 0.003 percent of muons should reach the Earth's surface, approximately 10,000 muons strike every square meter of the Earth's surface every second. Investigating this discrepancy illustrates time dilation due to their high velocity, as proven by Einstein’s theory of special relativity.

We will employ real-time transmission for certain data using a LoRaWAN network, while storing data collected at higher frequencies on flash memory and a microSD card for post-touchdown analysis. Our team emphasizes transforming collected data into a coherent narrative through various methods, including visual representation with charts and graphs, generating tables for variable comparison, and conducting numerical analysis.

The CDOSR team's secondary mission involves measuring atmospheric data and air pollution at different altitudes. This mission is vital for environmental and technical reasons, as the CanSat operates in a dynamic environment with rapidly changing atmospheric conditions such as temperature, humidity, and pressure. We also aim to conduct technical evaluations and material tests, balancing real-time transmission of UV and air quality data with detailed post-mission analysis of muon data.

Additionally, we are testing new materials, such as lightweight Cordura nylon for our parachute, correlating its performance with atmospheric data during descent. The microcontroller at the core of our CanSat will undergo rigorous performance evaluation by processing various atmospheric and cosmic data in real-world conditions. Lastly, our mission serves as a testbed for a modular sensor design, evaluating the efficiency of different sensor combinations and the feasibility of a unified processing core.
\subsubsection{Research expectations}

The CDOSR team aims to gain insights and knowledge from measuring atmospheric data and air pollution at different altitudes.

The team aims to optimize the CanSat's design and operation by measuring temperature, humidity, and pressure at different altitudes to ensure its survival and successful mission completion.

As the altitude increases, the atmospheric conditions undergo significant changes. The team expects a decrease in temperature of around 6.5 °C per kilometer, which is approximately the value of the vertical thermal gradient in the troposphere under standard conditions\endnote{
    {\href{https://en.wikipedia.org/wiki/Atmospheric\_temperature\#Temperature\_versus\_altitude}
    {https://en.wikipedia.org/wiki/Atmospheric\_temperature}}}. Moreover, using both linear and exponential Stevin's law\endnote{
    {\href{https://en.wikipedia.org/wiki/Vertical\_pressure\_variation}
    {https://en.wikipedia.org/wiki/Vertical\_pressure\_variation}}}, 
the team should detect a decrease in air pressure of approximately 12 hPa per 100 meters. As a consequence, there should be also a slight decrease in relative humidity since it is directly proportional to the air pressure. These insights will help the team to design and optimize the CanSat's systems to withstand the changing atmospheric conditions during the mission.

The team aims to gather data on UV radiation and air pollution at various altitudes to identify pollution sources and raise awareness of associated health risks.

The team aims to gain insights into data collection, transmission, and analysis for future space projects. We will equip the CanSat with specialized sensors to capture and analyze high-energy particles, particularly muons. The insights gained will be invaluable for future projects involving cosmic research and particle physics.

Overall, the CoderDojo Space Robotics project team expects to gain valuable insights and knowledge from the secondary mission of measuring atmospheric data and air pollution at different altitudes, contributing to the broader goal of promoting environmental sustainability and advancing space-related technology.

\subsubsection{Objectives for a successful mission}

The below objectives are to be achieved on launch day and post-launch analysis:
\begin{multicols}{2}[\vspace{-0.75\baselineskip}]
\begin{itemize}[leftmargin=1cm,itemindent=0.5cm, noitemsep, topsep=2pt, label=\ding{51}]
    \item Successful launch
    \item Live data transmission and  telemetry
    \item Successful parachute deploy
    \item All systems nominal (reliable sensor and location data)
    \item Descent rate between 5-10 \SI{}{\meter\per\second}
    \item Landing confirmation
    \item Recovery of the can
    \item Data analysis
    \item Generating reports
\end{itemize}
\end{multicols}

In conclusion, the primary mission of the CanSat project is to measure and transmit atmospheric data such as temperature, pressure, and altitude, while the secondary mission includes additional measurements such as humidity, UV radiation, air pollution, telemetry data and muon detection. 

Collecting atmospheric data is crucial for our space project, as it offers vital insights into the environment the CanSat encounters, influencing its design optimization and supporting sustainability. Understanding atmospheric variables like temperature, pressure, humidity, and UV radiation is key to ensuring the CanSat's effective operation and preventing damage to its components.

The data gathered at various altitudes will not only help us fine-tune the CanSat's design for enhanced performance but also allow for a successful mission outcome.

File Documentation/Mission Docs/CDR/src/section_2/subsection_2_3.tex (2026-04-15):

\subsection{Electrical design}

The electrical design of our payload relies on the use of custom-made PCBs due to the limited space available in its interior. We have developed custom PCBs designed using Autodesk's EAGLE software to ensure that all the necessary components fit properly. 

Using custom PCBs provides several advantages for the CanSat project. Firstly, it allows for a better fit of all the components in the limited space available. This can increase the overall efficiency of the payload by reducing the size and weight while still accommodating all the necessary components. Secondly, custom PCBs can also help to reduce the risk of damage to the components during the launch and landing phases of the mission. By integrating the components into the PCB design, they are better protected from shocks and vibrations. Finally, designing custom PCBs allows for greater flexibility and customization in the CanSat's design, making it possible to optimize its performance and tailor it to specific mission requirements.

\subsubsection{Electrical Interface}
The electrical interface of the CanSat is designed to ensure a robust and reliable connection between its various electronic components. The microcontroller, an ESP32, serves as the central hub for the electrical interface, supplying power and data connectivity to the array of sensors, transmitters, and other components on the Sensor and Communications Boards.

\begin{figure}[htbp]
\centering
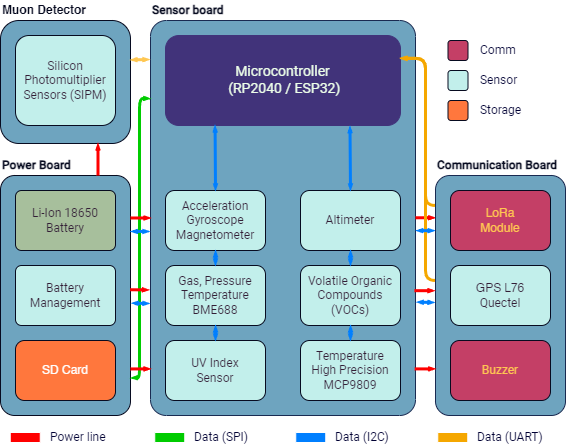
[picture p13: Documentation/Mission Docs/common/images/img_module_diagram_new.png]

\caption{\small{The Cansat block diagram with power and data lines.}}
\label{figmodule_diagrame}
\end{figure}

The compact form factor of the payload's mainboard is tailored to accommodate the ESP32 microcontroller. This component is chosen for its adequate computing power and integrated wireless communication capabilities, vital for the mission. To ensure compatibility and flexibility, multiple connection types are established between the microcontroller and other components, including UART, I2C, SPI, and other necessary digital inputs and outputs.

The environmental sensors, measuring atmospheric pressure, temperature, humidity, and UV index, are integrated onto the same PCB as the microcontroller to streamline data line connectivity, utilizing I2C connections for efficient communication. The Silicon Photomultiplier Sensors (SiPM) for muon detection communicate via the SPI/UART protocol. All data collected by the sensors are logged onto an onboard SD card and transmitted to the base station.

\begin{table}[htbp]
\centering
\arrayrulecolor{DeepSkyBlue4}
\begin{tabularx}{0.95\textwidth}{>{\raggedright\arraybackslash}p{3.5cm}c>{\raggedright\arraybackslash}X>{\raggedright\arraybackslash}p{5.5cm}}
\hline
\rowcolor{DeepSkyBlue4}
\textbf{\color{white!50}{Component}} & \textbf{\color{white!50}{Voltage}} & \textbf{\color{white!50}\textbf{Protocol}} & \textbf{\color{white!50}\textbf{Other Information}} \\ \hline
\rowcolors{2}{red}{}
ESP32-S3-Wroom or Raspberry Pi 20400& \SI{3.3}{\volt} & I2C, I2S, SPI, PWM, UART, USB & {Dual-core $\mu$Processor}\\ %\hline
% \rowcolor{LightCyan1!50}ESP32 Cam Board & \SI{3.3}{\volt} & I2C, SPI, PWM, UART & {Dual-core $\mu$Processor}\\ %$\hline
% Arduino Nano 33 BLE Sense & \SI{3.3}{\volt} & I2C, SPI, PWM, UART & {$\mu$Processor}\\ %\hline
\rowcolor{LightCyan1!50}LPS25H & \SI{3.3}{\volt} & I2C & Altimeter\\ %\hline
MPU-9250 & \SI{3.3}{\volt} & I2C & MEMS Module, 6-Axis Gyroscope,\/ Accelerometer,\/ Magnetometer\\ %\hline
\rowcolor{LightCyan1!50}BME688 & \SI{3.3}{\volt} & I2C & Air Quality Sensor, Humidity, Pressure \& Temperature Sensor\\ %\hline
MCP9808 & \SI{3.3}{\volt} & I2C & Temperature Sensor\\ %\hline
\rowcolor{LightCyan1!50}VEML6075 & \SI{3.3}{\volt} & I2C & Ambient Light Sensor\\ %\hline
Quectel L76 & \SI{3.3}{\volt} & UART, I2C & GNSS / GPS Module\\ %\hline
\rowcolor{LightCyan1!50}micro SD & \SI{3.3}{\volt} & SPI & Memory Card Connector\\ %\hline
LoRa Module& \SI{3.3}{\volt} & UART & Lora Modulation, \SI{868}{\mega\hertz} \\ %\hline
\rowcolor{LightCyan1!50}Power Switching Regulators & \SI{3.3}{\volt} & & High Efficiency Buck-Boost Converter  \\ %\hline
Low-dropout regulator& \SI{3.3}{\volt} & & Voltage regulator, \SI{868}{\mega\hertz} \\ %\hline
\rowcolor{LightCyan1!50}Muon detector & \SI{25}{\volt} & & Silicon Photomultiplier Sensor (SIPM)  \\ %\hline
\end{tabularx}
\caption{\small{Electronics Component Information}}
\end{table}

The power system is centered around a Li-Ion battery, managed by a battery management system to ensure optimal performance and safety. The microcontroller and low-power sensors are energized by a 3.3 Volt line from the Power Board. In contrast, the muon detector module, requiring a different voltage line, will be adequately supported by the power system design. The battery pack's voltage range, from 3.6V to 4.2V, is compatible with the system requirements. Voltage regulation is achieved through the use of buck-boost converters and low-dropout regulators, ensuring that all components receive the correct voltage. These converters are rated to deliver up to 2A of continuous current, enough to power the entire system without risk of overloading any component.

The operational time of the payload (for the single battery case) can be estimated with the given formula:

\begin{equation*}
\text{Time} = \frac{\text{Battery capacity} * \text{Voltage}}{\text{Power consumption}}=\frac{\SI{3400}{\milli\ampere} * \SI{4.2}{\volt}}{\SI{4.63}{\watt}} = \SI{3}{\hour} 
 05\text{min}
\end{equation*}

The duration of 3 hour is applicable when the payload's electronics operate at full capacity. With a dual battery system, this operational time significantly extends to well over 6 hours.

\begin{table}[htbp]
\centering
\arrayrulecolor{DeepSkyBlue4}
\begin{tabular}{>{\raggedright\arraybackslash}p{5cm}c>{\raggedleft\arraybackslash}p{2cm}
>{\raggedleft\arraybackslash}p{3cm}>{\centering\arraybackslash}p{2cm}>{\centering\arraybackslash}p{2cm}}
\hline
\rowcolor{DeepSkyBlue4}
\textbf{\color{white!50}{Component}} & \textbf{\color{white!50}{Voltage}} & \textbf{\color{white!50}\textbf{Current}} & \textbf{\color{white!50}\textbf{Power}} & \textbf{\color{white!50}\textbf{Mass}} \\ \hline
\rowcolors{2}{red}{}
ESP32 & \SI{3.3}{\volt} & \SI{40}-\SI{240}{\milli\ampere} & \SI{0.132}-\SI{0.792}{\watt} & \SI{2.15}{\gram}  \\
\rowcolor{LightCyan1!50}LPS25H & \SI{3.3}{\volt} & \SI{6}{\milli\ampere} & \SI{0.0198}{\watt} & \SI{0.8}{\gram}  \\
MPU-9250 & \SI{3.3}{\volt} & \SI{3.9}{\milli\ampere} &  \SI{0.01287}{\watt} &\SI{2.1}{\gram} \\
\rowcolor{LightCyan1!50}BME688 & \SI{3.3}{\volt} & \SI{3.9}{\milli\ampere} & \SI{0.01287}{\watt} & \SI{1.7}{\gram}  \\
MCP9808 & \SI{3.3}{\volt} & \SI{0.2}{\milli\ampere} &  \SI{0.00066}{\watt} &\SI{0.9}{\gram} \\
\rowcolor{LightCyan1!50}VEML76075 & \SI{3.3}{\volt} & \SI{0.12}{\milli\ampere} &  \SI{0.0004}{\watt} &\SI{0.8}{\gram}  \\
Quectel L76 (GPS) & \SI{3.3}{\volt} &  \SI{25}{\milli\ampere} &  \SI{0.0825}{\watt} & \SI{0.5}{\gram} \\
\rowcolor{LightCyan1!50}micro SD & \SI{3.3}{\volt} & \SI{0.2}{\milli\ampere} &  \SI{0.00066}{\watt} &\SI{1.6}{\gram} \\
LoRa Module & \SI{3.3}{\volt} & \SI{40}{\milli\ampere} &  \SI{0.132}{\watt} &\SI{4.15}{\gram} \\
\rowcolor{LightCyan1!50}Power Switching Regulators & \SI{3.3}{\volt} &\SI{800}{\milli\ampere}&  \SI{2.64}{\watt} &\SI{0.7}{\gram}\\
Low-dropout regulator & \SI{3.3}{\volt} &\SI{100}{\milli\ampere}&  \SI{0.3}{\watt} &\SI{0.6}{\gram}  \\
\rowcolor{LightCyan1!50}Muon detector & \SI{25}{\volt} & \SI{0.02}{\milli\ampere} & \SI{0.5}{\watt} &\SI{7}{\gram} \\ 
Buzzer & \SI{3.3}{\volt} &\SI{30}{\milli\ampere}&  \SI{0.09}{\watt} &\SI{3.15}{\gram}  \\
\rowcolor{DeepSkyBlue4}
\textbf{\color{white!50}{Total Power}} & & & \textbf{\color{white!50}{\SI{4.63}{\watt}}} & \textbf{\color{white!50}\SI{26.15}{\gram}}  \\
\hline
\end{tabular}
\caption{\small{Power consumption for the Major Electronics Components}}
\end{table}

\subsubsection{Power budget}

The payload is powered by a rechargeable Lithium-Ion battery pack with a 3.6 Volt output, supplying power to all of the components, with a maximum discharge of 8A. With an estimated power consumption of approximately \SI{1.25}{\ampere}, the battery pack's \SI{3400}{\milli\ampere\hour} (single battery) or \SI{6800}{\milli\ampere\hour} (dual batteries) capacity provides ample power for the entire mission. To ensure the payload has sufficient power throughout the mission, the battery is designed to provide over 3 hours of power supply to the system, even in the most power-consuming conditions. Moreover, after landing, the payload is programmed to switch to a lower power consumption mode, allowing for an extended battery life.

    % \begin{table}[htbp]
    %   \centering
    %   \arrayrulecolor{DeepSkyBlue4}
    %     \begin{tabular}{llcccc}
    %     \hline
    %     \rowcolor{DeepSkyBlue4}
    %     \textbf{\color{white!50}{Device}} &  \textbf{\color{white!50}{Voltage}} &  \textbf{\color{white!50}{Current (mA)}} & \textbf{\color{white!50}{Power (mW)}} & \textbf{\color{white!50}{Flight}} & \textbf{\color{white!50}{Ground}} \\
    %     \hline
    %     ESP32 Board & 5 & 20 & 100 & ON &ON \\
    %     AMS1117 Voltage Regulator & 5 & 69 & 117.3 & ON & ON \\
    %     LoRa RFM96 Module & 3.3 & 28 & 92.4 & ON & ON \\
    %     GPS NEO 6M-V2 & 3.3 & 11 & 36.3 & ON & ON \\
    %     BME280 & 3.3 & 0.36 & 1.2 & ON & ON \\
    %     ADXL345 (on GY801 Module) & 3.3 & 0.40 & 0.1 & ON & ON \\
    %     Noctua NF-A4x10 5V PWM Fan & 5 & 40 & 200 & ON & OFF \\
    %     Active buzzer & 5 & 30 & 150 & OFF & ON \\
    %     SPS30 PM Sensor & 5 & 55 & 275 & ON & ON \\
    %     NTC Current Mirror Circuit & 3.3 & 0.038 & 0.1 & ON & ON \\
    %     MicroSD Card Breakout Board & 3.3 & 30 (max) & 99 & ON & ON \\
    %     \hline
    %     Total Current (mA) & & & & 184.4 & 174.4 \\
    %     Total Power (mW) & & & & 921.4 & 871.4 \\
    %     \hline
    %     \end{tabular}%
    %       \caption{\small{Power Consumption of CanSat Components}}
    %   \label{tab:power-consumption}%
    % \end{table}

\subsubsection{RF Link}
The RF link is an essential component of any mission. It allows for real-time data transmission from the payload to the ground station, enabling the team to monitor the mission's performance and collect valuable data during the flight.

In our payload, we have chosen to utilize a single RF module, the LoRa communication module, to maintain a robust and reliable communication link. This module is responsible for transmitting vital data parameters such as GPS coordinates, temperature, pressure, altitude, and gas sensor readings back to the base station. It interfaces with the microcontroller via the UART protocol and is powered by a 3.3V supply. The current consumption of the LoRa module typically ranges around 100-150mA. It operates on the 868MHz frequency band, which is optimal for long-range transmission with low power consumption.

This approach simplifies the communication architecture, reducing potential points of failure and ensuring the payload maintains consistent communication with the ground station throughout its mission. The inherent redundancy of the LoRa network protocol also provides robustness against interference, contributing to the overall success of the mission and the integrity of the data collected.

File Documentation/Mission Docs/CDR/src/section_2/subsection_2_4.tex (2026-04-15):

\subsection{Software design}

The CanSat’s software has two main purposes. Firstly, it is designed to acquire and log data from various sensors. This includes communication with the hardware equipment and additional processing such as compensation, data manipulation, and various calculations to give the raw data some meaning. Secondly, the software is responsible for logging the acquired data onto onboard persistent storage and transmitting it to the ground station. The software is programmed to execute all of these tasks autonomously, in real-time with a high-speed performance, without the need for human intervention. The software has two main parts: initialization and operating mode. 

\subsubsection{Boot-up sequence}
During the initialization phase (boot-up), the system initializes by setting up various parameters and values to ensure proper functioning, and the software sets up the connected hardware, including sensors and data transmission devices, following a static set of instructions. Once the devices are set up, a startup message is sent on the data transmission channel to indicate that the system is online, and any errors encountered during this phase are logged.

\subsubsection{Runtime and data management}
After the initialization phase, the program enters the main loop, where it reads each sensor at a predefined period and processes the information. This loop spans almost the entire duration of the mission. Once the payload lands, the main loop is stopped, and the recovery loop starts. During this loop, only positional data is read, logged, or transmitted, and the recovery helper system is activated.

\subsubsection{Sensor interrogation}
The payload will collect various data from the sensors, with sensors being fetched every 150ms-250ms to maximize raw data throughput. Communication with the sensors is possible through the communication protocols described in section 2.3. To optimize efficiency and reduce the time spent on device communication handover, each sensor is strategically allocated to one of the two I2C buses provided by our selected microcontroller. This utilization of dual I2C lines allows for simultaneous data acquisition from multiple sensors without the need for bus arbitration, thereby enhancing the overall performance of our system.

\begin{table}[ht]
\centering
\arrayrulecolor{DeepSkyBlue4}
\begin{tabular}{ll}
\rowcolor{DeepSkyBlue4}
\hline
\textbf{\color{white!50}{Data Interface}} & \textbf{\color{white!50}{Components}} \\ \hline
USART/UART & Radio link module \\
& GNSS module \\ 
\rowcolor{LightCyan1!50}I2C & Accelerometer, Gyroscope, Pressure, \\
\rowcolor{LightCyan1!50} &Humidity, Temperature, CO$_2$/CO sensor \\
SPI & Micro SD memory card \\ 
%1-Wire & Temperature sensor \\ 
\rowcolor{LightCyan1!50}Analog & UV light sensor \\
\rowcolor{LightCyan1!50} & Muon detector (Sipm) \\
\hline
\end{tabular}
\caption{\small{Data interfaces used in CanSat with their corresponding components.}}
\label{tab:data-interfaces}
\end{table}

\subsubsection{Data Gathering and Storage}

To ensure data integrity and mitigate the risk of data loss, all logging will be conducted on the SD card. The data will be recorded in CSV format, which will include a timestamp for each reading to facilitate straightforward processing after retrieval. In addition to logging, data will be transmitted in real time via the LoRa communication module, enabling continuous monitoring of the payload's status and environmental readings. This dual approach of storing and transmitting data ensures that we maintain a comprehensive dataset for analysis post-mission while also keeping track of the payload's performance during its flight.

The data gathered includes:
\begin{itemize}
\item X, Y, and Z-axis readings from a gyroscope, magnetometer, and accelerometer (only logged);
\item Temperature readings (in Celsius) from the temperature sensor (transmitted and logged);
\item Barometric pressure readings (in Pascals) and relative humidity readings (in percentage) from the BME688 sensor (transmitted and logged);
\item UV Index readings (transmitted and logged);
\item Altitude readings (in meters) calculated from the barometric pressure sensor (transmitted and logged);
\item Muon counts from the SIPM module;
\item Main battery voltage readings (in volts) (transmitted).
\end{itemize}

The SD card is equipped with ample storage capacity to house all the collected data, including sensor readings and any images captured during the mission. The microcontroller communicates this data to the ground station in binary format, which not only conserves bandwidth due to the small size of the data packets but also promotes data security through the potential use of encryption prior to transmission. The efficiency of the data packet size contributes to a stable connection, ensuring smooth data transfer without issues. Even with a transmission rate of once per second, the cumulative data sent remains well below the 1 Mb mark, ensuring that storage and bandwidth resources are effectively utilized.

\subsubsection{Programming Language and Development Environment}

The microcontroller is the central component of the CanSat, responsible for managing all the peripherals connected through various media access and wire protocols. Each device requires specific commands and data retrieval procedures. Furthermore, every operation involving an external device must adhere to strict time constraints. For instance, a query to the temperature sensor must be processed before the next packet is sent across the wireless link to the ground station.

To ensure that these strict timing requirements are met, the CanSat firmware is based on a real-time operating system (RTOS). RTOS is ideal for mission-critical applications where I/O calls and system calls must be executed within a specific timeframe, and where errors must not cause the system to stop running. The ESP32 comes with FreeRTOS, which is the open-source de-facto standard for embedded applications. \ref{AE22}

We will be using Git extensively to keep track of changes to the codebase. This allows us to easily roll back to a previous version if a new feature breaks the code. With Git, we can collaborate on the codebase and track changes made by different team members, ensuring a smooth and efficient development process.

% \begin{wrapfigure}{r}{0.5\textwidth}
%     \centering
%     \includegraphics[width=7.5cm]{images/img_Cansat_RTOS.eps}
%     \caption{\small{CanSat software state diagram.}}
%     \label{fig:rtos}
% \end{wrapfigure}

Additionally, we are planning to develop a custom software application that will run on the ground station. This application will receive the telemetry data from the payload and interpret it, visualizing the information on real-time graphs. The software will extract sensor data such as acceleration, GPS coordinates, pressure, and more from the raw data packets, allowing us to monitor the payload's performance and the environmental conditions it encounters. The software will also log the data to ensure that no valuable measurements are lost.

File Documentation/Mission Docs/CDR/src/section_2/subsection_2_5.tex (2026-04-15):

\subsection{Recovery system}
Our recovery system was designed to slow down the descent rate of the payload, nose cone and body tube to a safe and controlled speed of which may vary depending on weather conditions (we will discuss it a bit later on). The payload’s recovery system ensures a safe and controlled descent to the ground via a deployed parachute after reaching maximum altitude.

\subsubsection{Parachute}

The key element is the hemispherical parachute.
\begin{wrapfigure}{l}{0.26\textwidth}
\centering

\caption{\small{Parachute design.}}
\label{fig:software_fiagram}
\end{wrapfigure}
This type is ideal since our mission involves only atmospheric descent, not targeted landings. The parachute deploys right after the payload is released from the helicopter, attaching to the can at six points to minimize rotation. Six durable, lightweight ropes (1 gram/meter) connect the parachute to the payload. A ball-bearing swivel is recommended to prevent line entanglement. We will use colorful nylon for visibility.

In addition, we have two secondary recovery systems: GPS for descent tracking and a loud buzzer activated upon landing when sensors detect no movement. The bright colors of the can and parachute will aid in locating the payload.

Our parachute system is designed for both prolonged descent (6 m/s) for atmospheric analysis in good weather and rapid descent (9 m/s) in poor weather. Calculations for descent rates factor in time to ensure successful recovery.

For the values in Tables 6 and 7, we used the following formulas:

\begin{equation}\label{eq1}
S=\frac{2mg}{C_d \rho v^2}, \quad\quad D = \sqrt{\frac{4S}{\pi}}, \quad\quad SLL = 1.15 * D, \quad\quad d = D * 10\%
\end{equation}

\begin{table}[htbp]
\centering
\arrayrulecolor{DeepSkyBlue4}
\begin{tabular}{>{\centering\arraybackslash}lcc}
\rowcolor{DeepSkyBlue4}
\hline
\textbf{\color{white!50}{Parameter}} & \multicolumn{1}{|c|}{\textbf{\color{white!50}{1st Parachute}}}  & \textbf{\color{white!50}{2nd Parachute}} \\
\hline
Surface & 0.0834 m$^{2}$ & 0.0370 m$^{2}$\\
\rowcolor{LightCyan1!50}Diameter 1 (D) & 0.3259 m $\approx$ 32.6 cm & 0.2173 m $\approx$ 21.7 cm \\
Diameter 2 (d) & 3.26 cm & 2.17 cm\\
\rowcolor{LightCyan1!50}Suspension Lines (SLL) & 37.5 cm & 25 cm \\
\hline
\end{tabular}
\caption{Surface and diameter for the Payload's parachutes}
\end{table}

\begin{table}[htbp]
\centering
\arrayrulecolor{DeepSkyBlue4}
\begin{tabular}{>{\centering\arraybackslash}lcc}
\rowcolor{DeepSkyBlue4}
\hline
\textbf{\color{white!50}{Parameter}} & \multicolumn{1}{|c|}{\textbf{\color{white!50}{3rd Parachute}}}  & \textbf{\color{white!50}{4th Parachute}} \\
\hline
Surface & 0.0444 m$^{2}$ & 0.0197 m$^{2}$\\
\rowcolor{LightCyan1!50}Diameter 1 (D) & 0.2380 m $\approx$ 23.8 cm & 0.1587 m $\approx$ 15.8 cm \\
Diameter 2 (d) & 2.38 cm & 1.58 cm\\
\rowcolor{LightCyan1!50}Suspension Lines (SLL) & 27.37cm & 18.17 cm \\
\hline
\end{tabular}
\caption{Surface and diameter for the nose cone and body tube's parachutes}
\end{table}

To calculate the dimensions required for the parachute, we considered the following constant parameters, including physical constants and canopy parameters (Table 8).

\begin{table}[htbp]
\centering
\arrayrulecolor{DeepSkyBlue4}
\begin{tabular}{>{\centering\arraybackslash}lc}
\rowcolor{DeepSkyBlue4}
\hline
\multicolumn{1}{|c|}{\textbf{\color{white!50}{Parameter}}}  & \textbf{\color{white!50}{Value}} \\
\hline
$g$ - gravitational acceleration & \SI{9.81 }{\meter\per\square\second} \\
\rowcolor{LightCyan1!50}$\rho$ - air density & \SI{1.225}{\kilogram\per\cubic\metre} \\
$v$ - descent velocity & 6 and 9 \SI{}{\meter\per\second} \\
\rowcolor{LightCyan1!50}$m$ - Payload mass & \SI{0.15}{\kilogram} \\
$m$ - nose cone and body tube mass & \SI{0.08}{\kilogram} \\
\rowcolor{LightCyan1!50}$C_d$ - Drag coefficient & 0.8 \\
$n$ - number of gores & 6 \\
\hline
\end{tabular}
\caption{Constant parameters and their values}
\end{table}

The hemispherical parachutes with 6 gores and an additional spill hole of diameter d = 10\% of the canopy’s diameter, D on the top, is our preferred primary recovery system due to its high drag coefficient per area, which allows for a lightweight parachute. This spill hole helps with air transition along the parachute, preventing oscillations during descent.

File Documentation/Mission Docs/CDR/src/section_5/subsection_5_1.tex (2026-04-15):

The risk analysis section of the project plan is vital, identifying potential risks to mission success and outlining mitigation strategies. It summarizes major risks and steps taken to address them:

\begin{itemize}[leftmargin=1cm, itemindent=0.25cm, noitemsep, topsep=0pt, label=$\bullet$]
\item \textbf{Communication failure}: Critical for mission success, factors like interference, distance, and line of sight affect communication quality. Mitigate risks through system checks, tests, and deployment procedures, including onboard self-diagnostics and LED confirmation.
\item \textbf{Power limitations}: Payload power generation and storage are limited. Ensure power-efficient design and sufficient power for mission completion.
\item \textbf{Environmental factors}: Payload faces various environmental challenges like temperature, humidity, and vibration. Design for resilience and verify mission objectives through endurance, high G-force simulation, and landing tests.
\item \textbf{Technical issues}: Prototype development board to catch design mistakes early. Identify and prepare contingency plans for potential technical challenges.
\item \textbf{Budget constraints}: Ensure project feasibility within budget constraints, prioritizing mission objectives accordingly.
\end{itemize}

\subsection{Resource estimation}
To ensure that the project is completed successfully within the given budget and timeframe, it is crucial to perform a thorough estimation of the required resources. This includes identifying the necessary materials, equipment, and team members needed to complete the project, as well as the associated costs and time requirements. 

By performing a detailed resource estimation, the project team can effectively plan and allocate resources to ensure that the project is completed on time, within budget, and to the desired quality standards. 

Below is a breakdown of the resources required for the CanSat project:
\begin{itemize}[leftmargin=1cm, itemindent=0.25cm, noitemsep, topsep=0pt, label=$\bullet$]
\item Materials and components:
\begin{itemize}[label=\ding{111}, noitemsep, topsep=1pt]
\item Identify and list out all the required materials and components, including a microcontroller, sensors, batteries, antennas, radio modules, lightweight printable plastics, and other miscellaneous parts
\item Cost of materials can vary depending on the quality and quantity of components required
\end{itemize}
\item Tools and equipment:
\begin{itemize}[label=\ding{111}, noitemsep, topsep=1pt]
\item Various tools and equipment required, such as multimeters, 3d printers, oscilloscope, soldering station, and other miscellaneous parts
\end{itemize}
\item Software:
\begin{itemize}[label=\ding{111}, noitemsep, topsep=1pt]
\item Programming microcontrollers, designing 3D concepts, and analyzing data collected by the sensors
\item Using open-source software can significantly reduce the costs associated with software for the project.
\end{itemize}
\item Manpower and build time:
\begin{itemize}[label=\ding{111}, noitemsep, topsep=1pt]
\item Online tools and weekly meetings are used to ensure accuracy
\item Estimated effort of 630 hours for the entire project.
\end{itemize}
\item Testing and validation:
\begin{itemize}[label=\ding{111}, noitemsep, topsep=1pt]
\item Essential step to ensure the project performs as expected
\item May include the use of specialized equipment such as a drone or rocket
\end{itemize}
\item Shipping, transport, and logistics:
\begin{itemize}[label=\ding{111}, noitemsep, topsep=1pt]
\item Shipping and logistics costs may need to be factored into the project’s budget
\item May include shipping materials and components and travel costs for team members to attend the competition
\end{itemize}
\item Miscellaneous costs:
\begin{itemize}[label=\ding{111}, noitemsep, topsep=1pt]
\item Other costs that may need to be considered when estimating resources for the project
\end{itemize}
\end{itemize}

In conclusion, it is evident that a successful project outcome is heavily reliant on a proper estimation of resources required to complete the project. Neglecting the factors such as materials, components, tools, equipment, software, testing and validation, shipping and logistics, and other unforeseen costs can lead to budget overruns, delays, and ultimately failure to achieve project objectives.

\subsubsection{Budget}

We conducted thorough research to ensure that our budget aligns with the ideal specifications for our CanSat. This involved finding the most efficient and lightweight components without compromising performance, as well as maximizing battery life. By carefully considering each part, we aimed to optimize our budget and ensure that we could achieve our project objectives.

However, building the CanSat is just a part of the project. Therefore, our budget covers the entire project from start to finish, which can be divided into four main parts: 
\begin{itemize}[leftmargin=1cm, itemindent=0.25cm, noitemsep, topsep=0pt, label=$\bullet$]
    \item \textbf{Hardware parts}: all the necessary mechanical and electronic/electrical parts required to build both our custom development board and final payload. The cost estimation includes the purchase of a microcontroller, sensors, batteries, antennas, radio modules, lightweight printable plastics, and other miscellaneous parts.
    \item \textbf{Publicity and Branding}: covers the creation of custom t-shirts to promote our team and the event. In addition to custom t-shirts, we will also invest in creating promotional materials such as flyers, posters, and banners that showcase our team and the mission. These materials will be distributed both digitally and in person to help increase awareness of our project and the competition. Additionally, we will allocate a portion of our budget towards branding efforts such as website design and social media management to maintain a consistent and professional image for our team. Investing in Publicity and Branding will help us build a strong reputation within the community and attract potential sponsors and supporters to our cause.
    % \item \textbf{Travel Expenses}: includes the transportation costs, with tickets for the team to travel to the Competition Venue. This includes the cost of transportation by train, as well as any necessary local travel expenses.
    \item \textbf{Emergency Funds}: a contingency budget to cover any unforeseen costs that may arise during the project.
\end{itemize}

Below is a table that outlines all the anticipated expenses associated with the CanSat mission. This includes the costs of the components used to construct the CanSat, as well as any supplementary materials, equipment, and personnel necessary to complete the mission.

The components required for the project will be purchased from various suppliers such Optimus Digital, Cle\c{s}te.ro, Mouser, TME, Adafruit, and JLCPCB. It is worth noting that the team did not receive any kits from the organizers, and as a result, the team members did all the design and construction of the payload.

\begin{table}[htbp]
\centering
\arrayrulecolor{DeepSkyBlue4}
\begin{tabular}{>{\centering\arraybackslash}p{4.5cm}>{\centering\arraybackslash}lc}
\rowcolor{DeepSkyBlue4}
\hline
\multicolumn{1}{c}{\textbf{\color{white!50}{Category}}}& \multicolumn{1}{c}{\textbf{\color{white!50}{Cost Item}}} & \textbf{\color{white!50}{Cost \texteuro}} \\
\hline
\multicolumn{1}{l}{Hardware Parts (deductible) (134\texteuro)}& ESP32 ($\mu$C) & 6 \\
& \cellcolor{LightCyan1!50}LPS25H - Altimeter & \cellcolor{LightCyan1!50}25 \\
& MPU 9250 - IMU Sensor & 5 \\
& \cellcolor{LightCyan1!50}BME688 - Barometric Pressure & \cellcolor{LightCyan1!50}10 \\
& MCP9808 - Temperature Sensor & \cellcolor{LightCyan1!50}5 \\
& \cellcolor{LightCyan1!50}VEML6075 - UVA UVB UV Sensor & 5 \\
& Quectel L76 - GPS & 10 \\
& Power Switching regulators, LDO & 4 \\
& \cellcolor{LightCyan1!50}micro SD & \cellcolor{LightCyan1!50}6 \\
& Buzzer & 1 \\
& SMA Connectors & 2 \\
& \cellcolor{LightCyan1!50}Radio module & \cellcolor{LightCyan1!50}10 \\
& Parachute material & 20 \\
& Battery & 25 \\
\multicolumn{1}{l}{Consumables (non-deductible)}&  \cellcolor{LightCyan1!50}PCB components (RLC, diodes) & \cellcolor{LightCyan1!50}10 \\
& \cellcolor{LightCyan1!50}Parachute cords & \cellcolor{LightCyan1!50}5 \\
& \cellcolor{LightCyan1!50}Antennas & \cellcolor{LightCyan1!50}10 \\
& 3D printer filament & 15 \\
\multicolumn{1}{l}{Publicity \& Branding (100 \texteuro)}& \cellcolor{LightCyan1!50}T-Shirts & \cellcolor{LightCyan1!50}65 \\
& \cellcolor{LightCyan1!50}Flyers \& stickers & \cellcolor{LightCyan1!50}10 \\
% \multicolumn{1}{l}{Travel Expenses (315 \texteuro)} & Train tickets & 205 \\
% & \cellcolor{LightCyan1!50} Meals & \cellcolor{LightCyan1!50}110 \\
\multicolumn{1}{l}{Emergency Funds}& Miscellaneous & 100 \\
\hline
& \textbf{Total} & \textbf{349} \\
\hline
\end{tabular}
\caption{Foreseen costs for the CanSat mission.}
\label{tab:costs}
\end{table}

\subsubsection{External support}
The successful execution of the CanSat mission relies on the assistance and resources given by different organizations, departments, and companies. We are fortunate to have received sponsorship or in-kind support from the following entities:
\begin{itemize}[leftmargin=1cm, itemindent=0.25cm, noitemsep, topsep=0pt, label=$\bullet$]
    % \item \textbf{CoderDojo Oradea} has provided substantial financial aid, technical support, and feedback on both hardware and software. This makes them our biggest sponsor so far, allowing us to acquire all of the most expensive components of our CanSat and facilities where we can carry out our activities;
    \item \textbf{Funda\c{t}ia Comunitar\u{a} Oradea} has generously provided facilities where we can conduct our activities;
    % \item \textbf{EduTrust} has provided both financial support and working facilities for our team;
    % \item \textbf{Elektrobit} has provided financial support, access to facilities, equipment, and expertise in Embedded systems;
    \item \textbf{Depozitul de Tricouri} has agreed to provide customized T-shirts for each team member, which will help us promote our team and the event.
\end{itemize}

\subsection{Test plan}

The mission's success hinges on thorough pre-launch testing. This plan outlines tests to ensure the payload meets objectives and functions under various conditions, categorized into mechanical, software, communication, power, integration, ground station, battery charging, launch, and post-mission tests. The goal is to ensure accurate data collection and transmission, and survival during launch and landing. Annex G provides a testing roadmap with general ideas for each test.

Specific tests on electronics and structure are crucial to verify sensor functionality and structural integrity under launch, landing, and environmental conditions (see Annex H). Endurance tests assess the payload's ability to withstand harsh conditions, such as falls, vibration, shock, and prolonged G-forces during transport, providing insights into its performance limits (see Annex I).

By conducting these tests, the team ensures the CanSat is fully functional and mission-ready.

\subsection{Time management}
To keep the project on track and meet our timeline, we have divided the process into several phases, each with specific tasks and durations. We have completed the ideation phase and are currently in the design and prototyping stages. The upcoming phases include various testing campaigns and construction runs. The exact details of the testing phase will be determined as the project progresses, leading up to the final phase, which culminates in the competition.

We estimate a total of 630 man-hours needed for the entire project and have already invested 330 hours. The Gantt chart automatically updates as we advance through the project, allowing us to monitor progress and adjust our plans as necessary to ensure timely completion. By using this tool, we can stay on schedule and achieve our desired outcomes.

% We have started testing Jira in parallel with using TeamGantt.com to implement an Agile framework for future competitions. Jira is a project management software that provides a flexible and powerful platform for managing projects using an Agile framework. 

% By implementing Jira, we can create a central location for tracking tasks, issues, and progress throughout the project lifecycle. This will allow us to easily collaborate and communicate with team members and stakeholders, as well as prioritize tasks and adjust schedules based on changing requirements or circumstances. In addition, Jira offers a range of reporting and analytics features, providing valuable insights into team performance, task completion rates, and potential bottlenecks. With Jira, we can also track time and effort spent on each task, which will help us better estimate future efforts and improve our planning and scheduling for future competitions. By using both Jira and TeamGantt.com, we can optimize our project management process and ensure efficient, effective completion of the CanSat project.

To ensure that we complete all necessary tasks on time, the following is a summary of our timeline. For a more detailed timeline, please refer to the Gantt chart provided in the Appendix.

\begin{itemize}[leftmargin=1cm, itemindent=0.25cm, noitemsep, topsep=0pt, label=$\bullet$]
\item Team formation: 11.10.2023 - 19.11.2023
\begin{multicols}{2}[\vspace{-0.75\baselineskip}]
\begin{itemize}[label=\ding{59}, noitemsep, topsep=2pt]
\item Think of feasible mission objectives and requirements
% \item CanSat Application Work \& Registration
\end{itemize}
\end{multicols}
\vspace*{-0.75\baselineskip}
\item Ideation: 11.10.2023 - 28.04.2024
\begin{multicols}{2}[\vspace{-0.75\baselineskip}]
\begin{itemize}[label=\ding{59}, noitemsep, topsep=2pt]
\item Documentation writing (PDR, CDR, FDR)
\item Mission refinements
\end{itemize}
\end{multicols}
\vspace*{-0.75\baselineskip}
\item Design the Rocket and Payload: 03.01.2024 - 19.05.2024
\begin{multicols}{2}[\vspace{-0.75\baselineskip}]
\begin{itemize}[label=\ding{59}, noitemsep, topsep=2pt]
\item Mechanical structure 
\item Electrical system
\item Software
\item Recovery system
\item Ground support
\end{itemize}
\end{multicols}
\vspace*{-0.75\baselineskip}
\item Prototyping: 22.01.2024 - 17.04.2024
\item Testing (prototype): 01.04.2024 - 30.04.2024
\item Build the CanSat: 08.04.2024 - 15.05.2024
\item Launch Campaign: 29.05.2024 - 02.06.2024
\end{itemize}

% Our program takes into account the potential issues that may arise at each phase and the time required to address them. However, unforeseen events may occur during the project, and as such, we have developed measures for prevention and risk mitigation, which are detailed below.

% \begin{table}[htbp]
% \centering
% \arrayrulecolor{DeepSkyBlue4}
% \begin{tabular}{>{\raggedright\arraybackslash}p{8cm}>{\raggedright\arraybackslash}p{7cm}}
% \rowcolor{DeepSkyBlue4}
% \hline
% \multicolumn{1}{c}{\textbf{\color{white!50}{Major risks}}} & \multicolumn{1}{c}{\textbf{\color{white!50}{Mitigation}}} \\
% \hline
% Delays in obtaining mandatory materials and electronic components due to the global semiconductor chip shortage, resulting in unavailability and delivery delays & Place orders for materials and electronic components well in advance, find alternative components and adjust the project timeline accordingly \\
% \rowcolor{LightCyan1!50}Overtime required for the electrical design part due to thorough testing and prototyping of the onboard circuits before integration into the final design & Create a good electrical schematic and perform exhaustive checks before beginning the physical build to catch any errors \\
% Unforeseen technical difficulties that may require additional troubleshooting time and access to technical guidance from partners & Grant some extra time for troubleshooting and have access to technical guidance from our partners \\
% \rowcolor{LightCyan1!50}Adverse weather conditions during testing & Analyze the weather status in advance and plan at least one backup day for testing \\
% CanSat damage during testing due to inappropriate launch sites and lack of safety measures & Carefully choose the launch site when testing the CanSat and ensure that all safety measures are met \\
% \rowcolor{LightCyan1!50}Recovery failure due to poor GPS transmission and weak buzzer sound & Before launching, ensure that the GPS transmission is strong and the buzzer sound is loud \\
% Team member availability: Unexpected absences or departures of team members could delay the project and lead to workload imbalances & Clear communication and expectations among team members, cross-training team members on critical tasks, and having backup plans for key roles \\
% \hline
% \end{tabular}
% \caption{Unforeseen events and risk mitigation.}
% \label{tab:risks}
% \end{table}

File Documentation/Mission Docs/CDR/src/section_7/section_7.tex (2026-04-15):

\section{Conclusion}

While we are confident in the success of the project, time constraints are currently a challenge that requires us to focus on testing each module and the system as a whole. Based on the results of our tests, we will need to adjust our design for the final version of the CanSat. 

We are mindful of the significant number of work hours required to implement and test all the features we want, but we are making good progress, and if we continue at our current pace, we believe that the project will be successful, and we will achieve our goal of winning the competition.

% \input{section_7/subsection_7_1}
\input{section_7/subsection_7_2}

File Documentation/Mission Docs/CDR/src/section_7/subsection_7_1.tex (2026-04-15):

% \subsection{Summary of the PDR}
% In this section, we will provide a brief summary of the Preliminary Design Review (PDR) for our Rocketry/CanSat mission. The PDR covers a range of topics, including the mission objectives, construction of the CanSat, electrical design, software development, risk mitigation strategies, data analysis plan, and outreach program. We will highlight the key aspects of each of these areas and provide an overview of the overall mission.

% \begin{itemize}[leftmargin=1cm, itemindent=0.25cm, noitemsep, topsep=0pt, label=$\bullet$]
% \item[I.] Introduction
% \begin{itemize}[label=$\bullet$, noitemsep, topsep=2pt]
% \item Details of the CanSat mission to analyze a planet's environment, including air quality, light conditions, wind speeds, terrain type, temperature, pressure, and live video to explore it further.
% \item The team members' roles and responsibilities, including team leader, embedded software developer, mission data analyst, mechanical and structural designer, and hardware developer and designer.
% \item Two primary missions: measuring air pollution and analyzing a potentially habitable planet by taking samples to assess the sustainability of life.
% \end{itemize}
% \item[II.] CanSat description
% \begin{itemize}[label=$\bullet$, noitemsep, topsep=2pt]
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

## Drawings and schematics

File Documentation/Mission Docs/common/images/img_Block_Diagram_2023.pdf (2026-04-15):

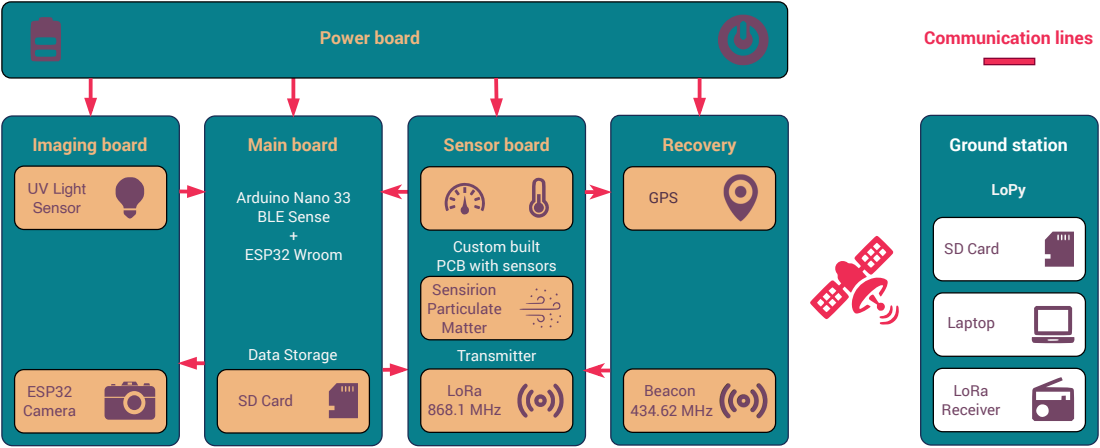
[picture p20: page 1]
Imaging board; ESP32; Camera; SD Card; Main board; Sensor board; Communication lines; Beacon 434.62 MHz; Recovery; LoRa 868.1 MHz; Ground station; Power board; LoRa Receiver; Laptop; Data Storage; GPS; LoPy; UV Light; Sensor; Arduino Nano 33; BLE Sense + ESP32 Wroom

Custom built
PCB with sensors
Sensirion
Particulate
Matter
Transmitter

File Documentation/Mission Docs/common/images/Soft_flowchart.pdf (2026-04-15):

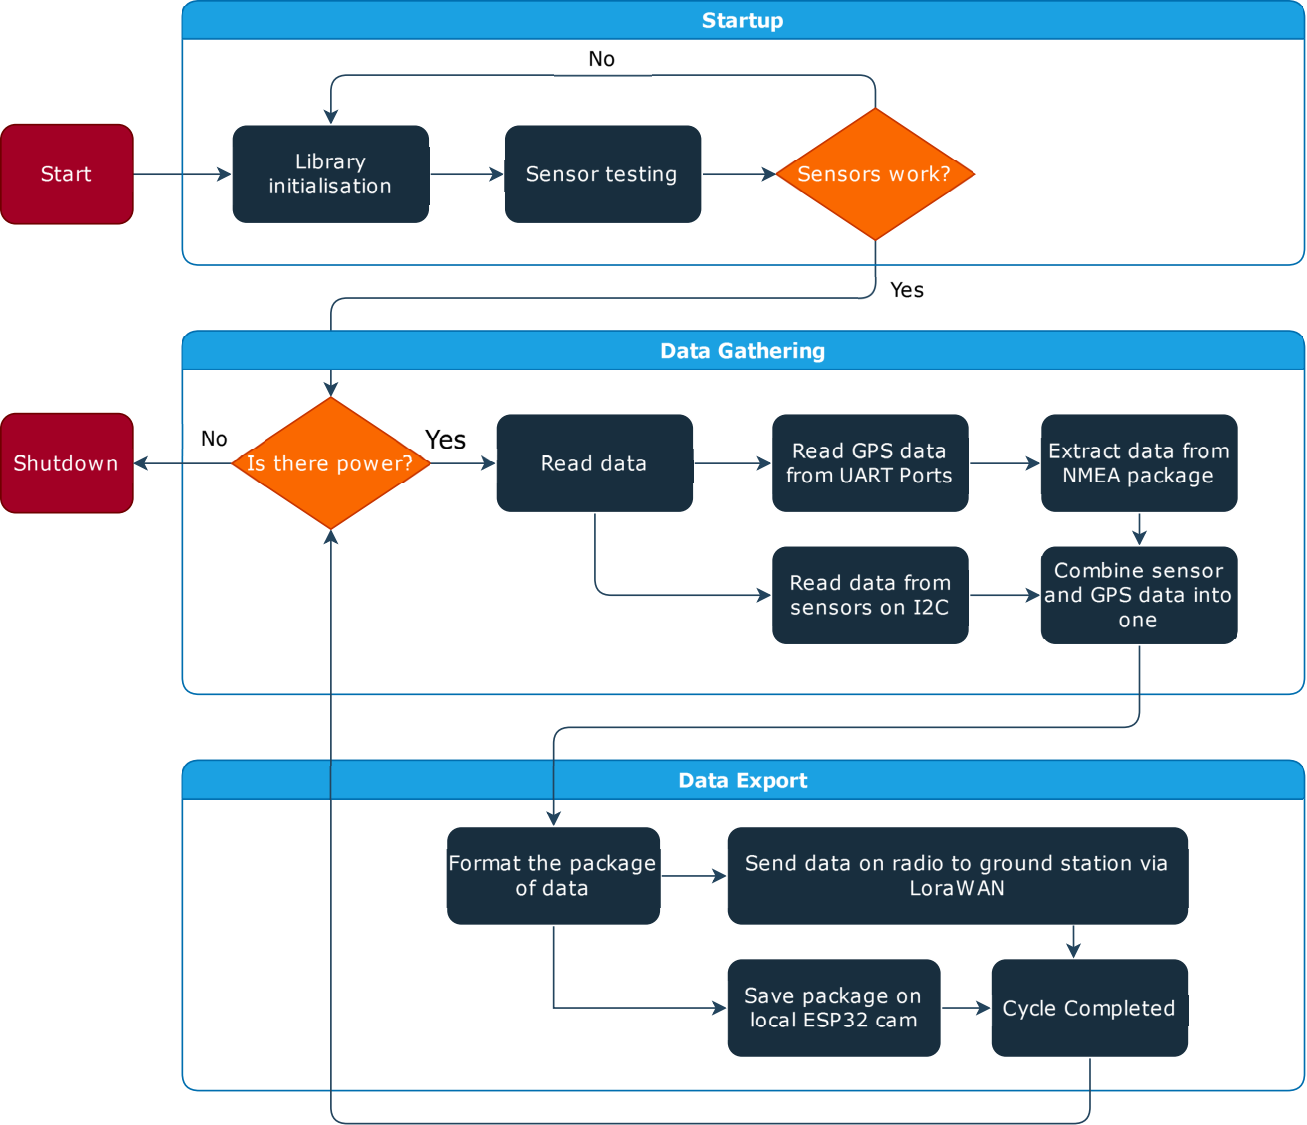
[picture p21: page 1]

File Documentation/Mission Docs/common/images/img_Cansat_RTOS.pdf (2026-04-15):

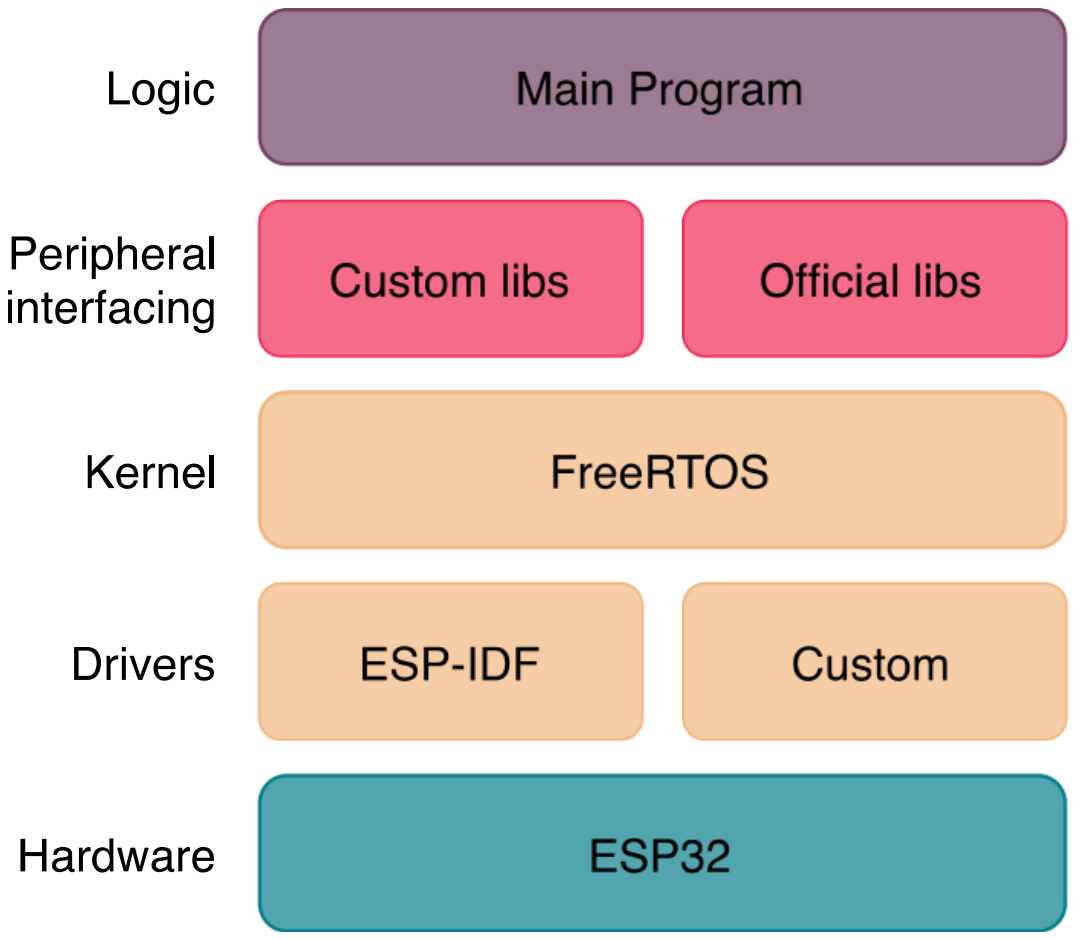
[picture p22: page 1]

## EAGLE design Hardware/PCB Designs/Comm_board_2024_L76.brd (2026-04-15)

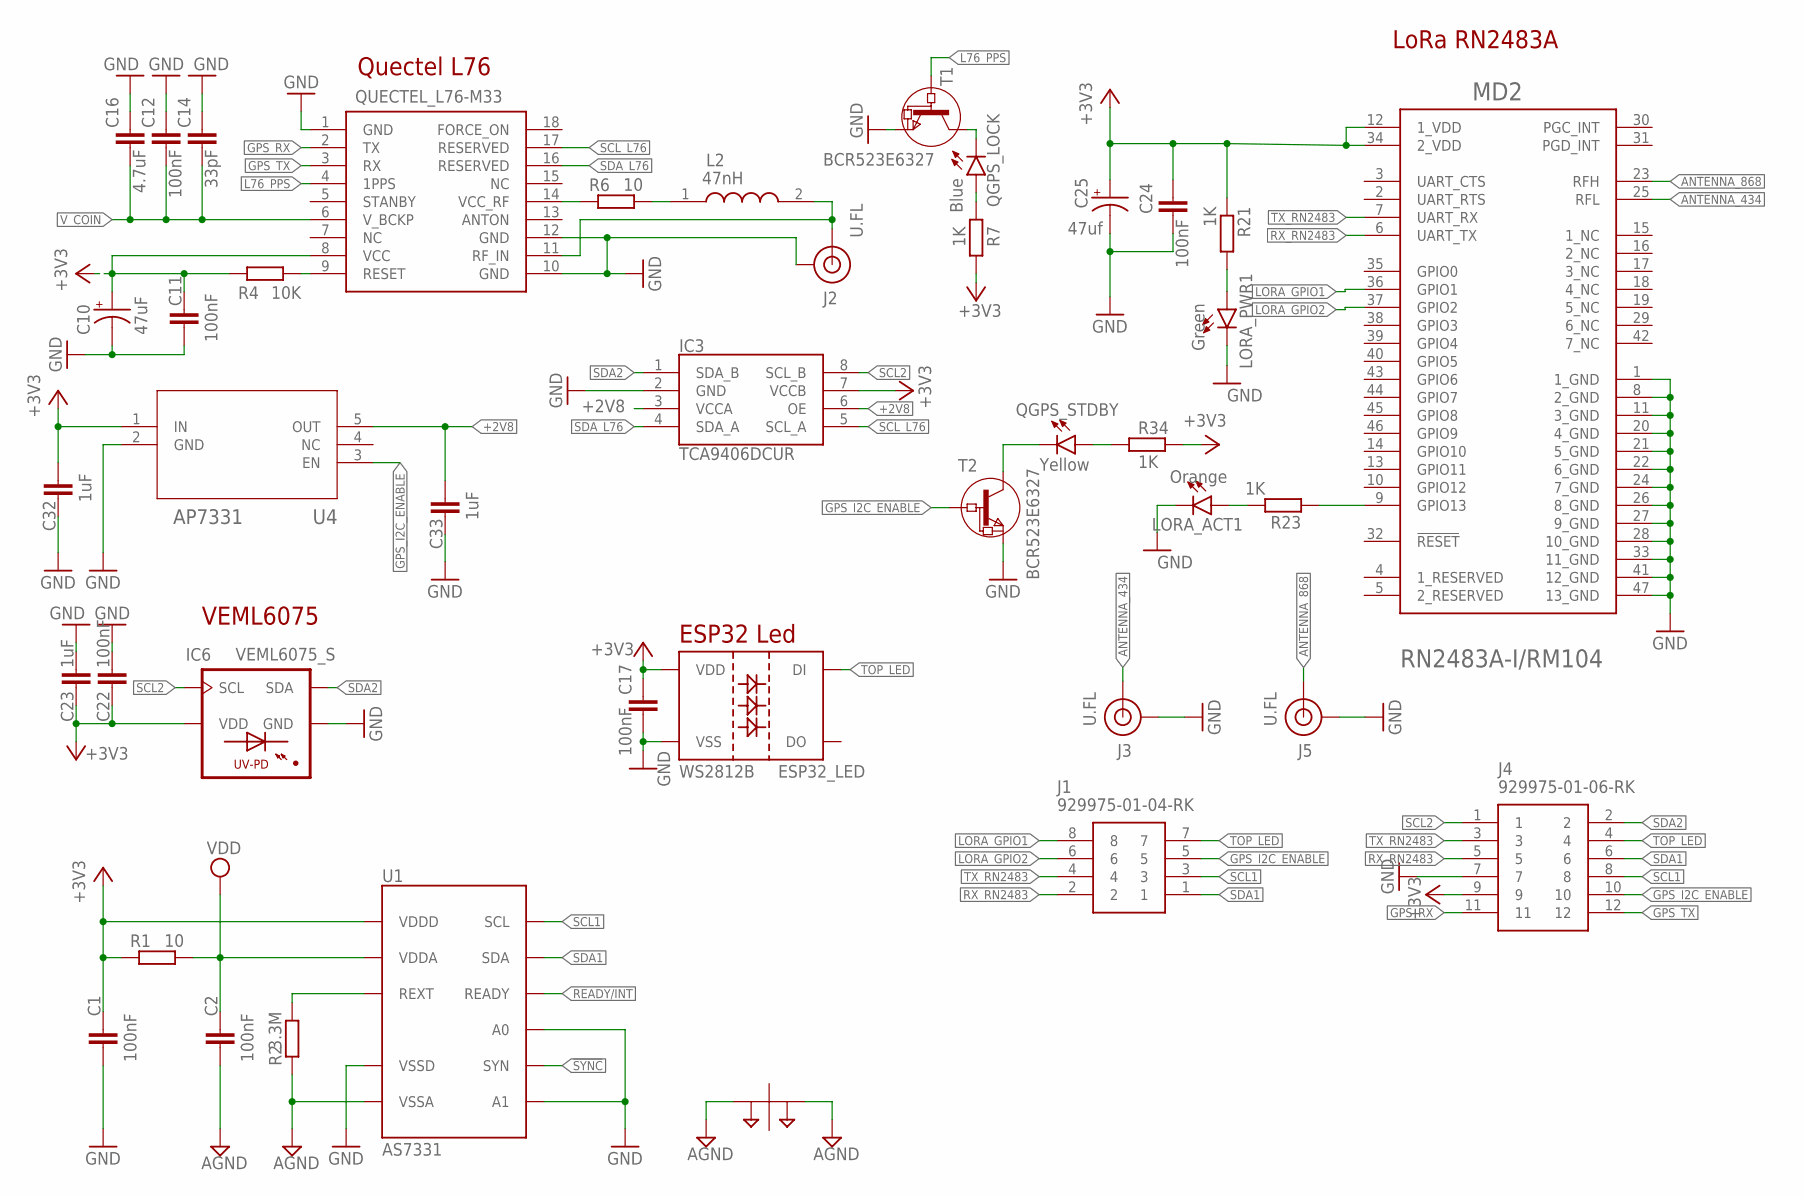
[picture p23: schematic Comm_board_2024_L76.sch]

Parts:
C1, C2, C11, C12, C17, C22, C24: 100nF; C0603
C10: 47uF; CAPMP6032X250N
C14: 33pF; C0603
C16: 4.7uF; C0603
C23, C32, C33: 1uF; C0603
C25: 47uf; CAPMP6032X250N
ESP32_LED: WS2812B
IC3: TCA9406DCUR; SOP50P310X90-8N
IC6: VEML6075_S; VISHAY_VEML6075_1.25X2X1
J1: 929975-01-04-RK; RHDR8W76P254_2X4_1016X508X839P
J2, J3, J5: U.FL; SPARKFUN-CONNECTORS_SPARKFUN-CONNECTORS_U.FL
J4: 929975-01-06-RK; RHDR12W76P254_2X6_1524X508X839
L2: 47nH; LQW2UAS12NG00L
LORA_ACT1: Orange; CHIP-LED0603
LORA_PWR1: Green; CHIP-LED0603
MD2: RM104_MICROCHIP_RN2483A-I-RM104MICROCHIP_RN2483A-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; RM104_MICROCHIP_RN2483A-I-RM104_0
QGPS_LOCK: Blue; CHIP-LED0603
QGPS_STDBY: Yellow; CHIP-LED0603
QUECTEL_L76-M33: L76 - M33; L76-M33
R1, R6: 10; R0603
R2: 3.3M; R0603
R4: 10K; R0603
R7, R21, R23, R34: 1K; R0603
SUPPLYTIE1: SPARKFUN-POWERSYMBOLS_2PT_GND_TIE
T1, T2: BCR523E6327; SOT-23
U1: AS7331; SPARKFUN_QWIIC_UV_SENSOR_AS7331_OLGA16
U4: AP7331; SOT25_DIO

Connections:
!SYNC: U1.8 (SYN)
+2V8: C33.2, IC3.3 (VCCA), IC3.6 (OE), U4.5 (OUT)
+3V3: C1.2, C10.1 (+), C11.2, C17.1, C22.2, C23.1, C24.1, C25.1 (+), C32.2, ESP32_LED.1 (VDD), IC3.7 (VCCB), IC6.4 (VDD), J4.9, MD2.12 (1_VDD), MD2.34 (2_VDD), QUECTEL_L76-M33.8 (VCC), R1.1, R4.1, R7.1, R21.1, R34.2, U1.10 (VDDD), U4.1 (IN)
AGND: C2.1, R2.1, SUPPLYTIE1.P$1, SUPPLYTIE1.P$2, U1.1 (VSSA), U1.2 (VSSA), U1.5 (VSSA), U1.6 (VSSA), U1.15 (VSSA), U1.16 (VSSA)
ANT1: J2.FEED (SIGNAL), L2.2, QUECTEL_L76-M33.11 (RF_IN)
ANTENNA_434: J3.FEED (SIGNAL), MD2.25 (RFL)
ANTENNA_868: J5.FEED (SIGNAL), MD2.23 (RFH)
GND: C1.1, C10.2 (-), C11.1, C12.2, C14.2, C16.2, C17.2, C22.1, C23.2, C24.2, C25.2 (-), C32.1, C33.1, ESP32_LED.3 (VSS), IC3.2 (GND), IC6.1 (GND), J2.1 (GND), J2.2 (GND), J2.3 (GND), J3.1 (GND), J3.2 (GND), J3.3 (GND), J4.7, J5.1 (GND), J5.2 (GND), J5.3 (GND), LORA_ACT1.C, LORA_PWR1.C, MD2.1 (1_GND), MD2.8 (2_GND), MD2.11 (3_GND), MD2.20 (4_GND), MD2.21 (5_GND), MD2.22 (6_GND), MD2.24 (7_GND), MD2.26 (8_GND), MD2.27 (9_GND), MD2.28 (10_GND), MD2.33 (11_GND), MD2.41 (12_GND), MD2.47 (13_GND), QUECTEL_L76-M33.1 (GND), QUECTEL_L76-M33.10 (GND), QUECTEL_L76-M33.12 (GND), T1.2 (E), T2.2 (E), U1.7 (A1), U1.11 (VSSD), U1.14 (A0), U4.2 (GND)
GPS2_RESET: QUECTEL_L76-M33.9 (RESET), R4.2
GPS_I2C_ENABLE: J1.5, J4.10, T2.3 (B), U4.3 (EN)
GPS_RX: J4.11, QUECTEL_L76-M33.2 (TX)
GPS_TX: J4.12, QUECTEL_L76-M33.3 (RX)
L76_PPS: QUECTEL_L76-M33.4 (1PPS), T1.3 (B)
LORA_GPIO1: J1.8, MD2.36 (GPIO1)
LORA_GPIO2: J1.6, MD2.37 (GPIO2)
unnamed: QGPS_LOCK.C, T1.1 (C)
unnamed: R2.2, U1.4 (REXT)
unnamed: QGPS_STDBY.C, T2.1 (C)
unnamed: L2.1, R6.2
unnamed: QGPS_STDBY.A, R34.1
unnamed: QUECTEL_L76-M33.14 (VCC_RF), R6.1
unnamed: QGPS_LOCK.A, R7.2
unnamed: MD2.9 (GPIO13), R23.1
unnamed: LORA_ACT1.A, R23.2
unnamed: LORA_PWR1.A, R21.2
READY/INT: U1.9 (READY)
RX_RN2483: J1.2, J4.5, MD2.6 (UART_TX)
SCL1: J1.3, J4.8, U1.13 (SCL)
SCL2: IC3.8 (SCL_B), IC6.3 (SCL), J4.1
SCL_L76: IC3.5 (SCL_A), QUECTEL_L76-M33.17 (RESERVED)
SDA1: J1.1, J4.6, U1.12 (SDA)
SDA2: IC3.1 (SDA_B), IC6.2 (SDA), J4.2
SDA_L76: IC3.4 (SDA_A), QUECTEL_L76-M33.16 (RESERVED)
TOP_LED: ESP32_LED.4 (DI), J1.7, J4.4
TX_RN2483: J1.4, J4.3, MD2.7 (UART_RX)
VDD: C2.2, R1.2, U1.3 (VDDA)
V_COIN: C12.1, C14.1, C16.1, QUECTEL_L76-M33.6 (V_BCKP)

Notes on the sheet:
Quectel L76
ESP32 Led
VEML6075
LoRa RN2483A

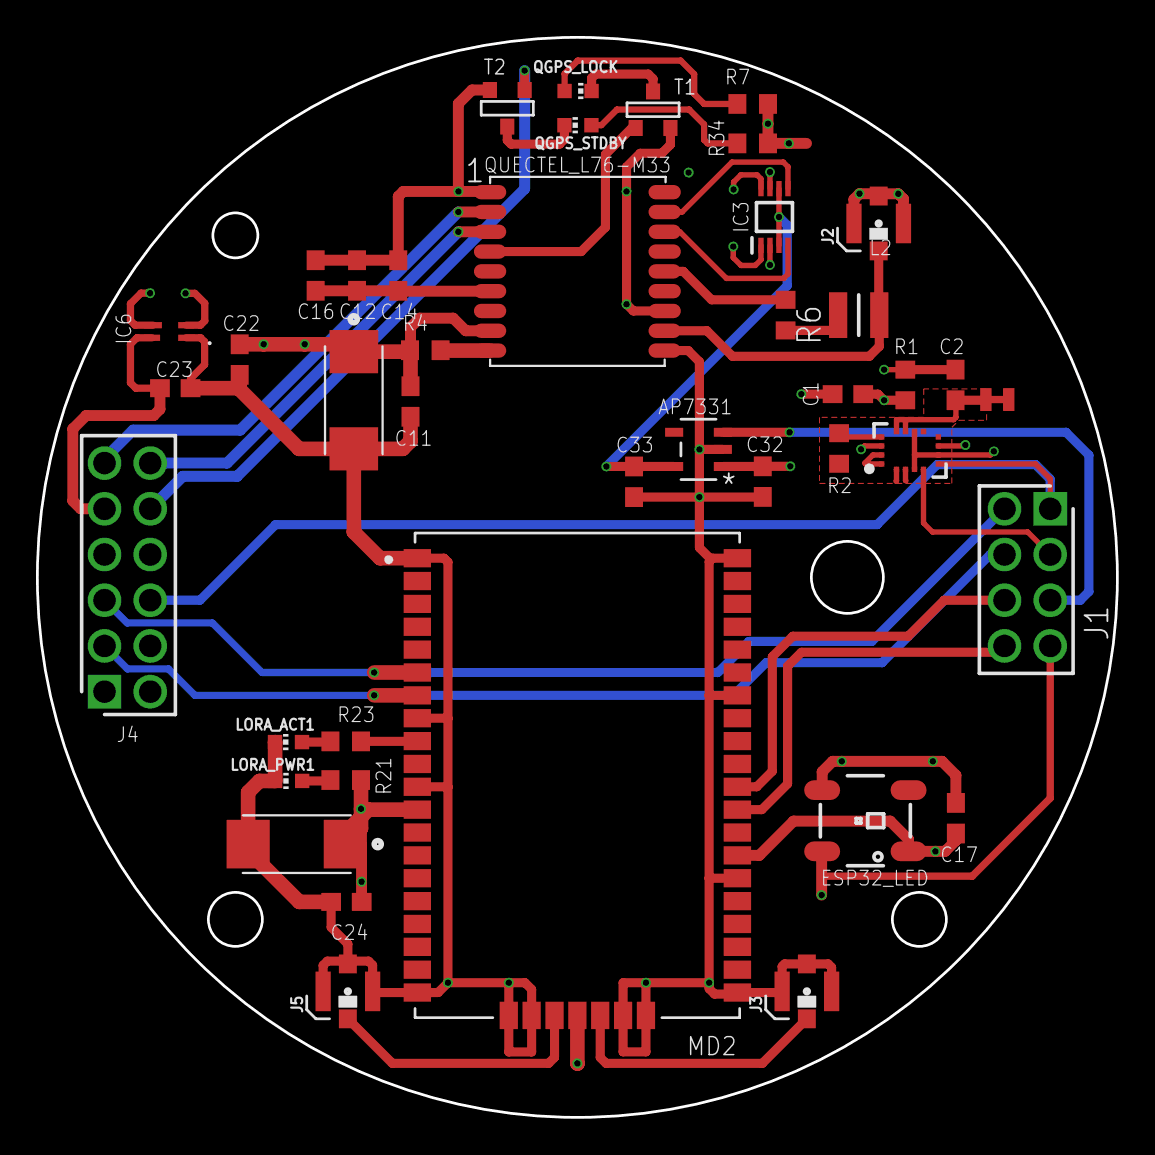
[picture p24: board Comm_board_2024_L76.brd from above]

Board: 4 copper layers, 60.0 x 60.0 mm, 42 parts (0 on the bottom side), 35 nets.

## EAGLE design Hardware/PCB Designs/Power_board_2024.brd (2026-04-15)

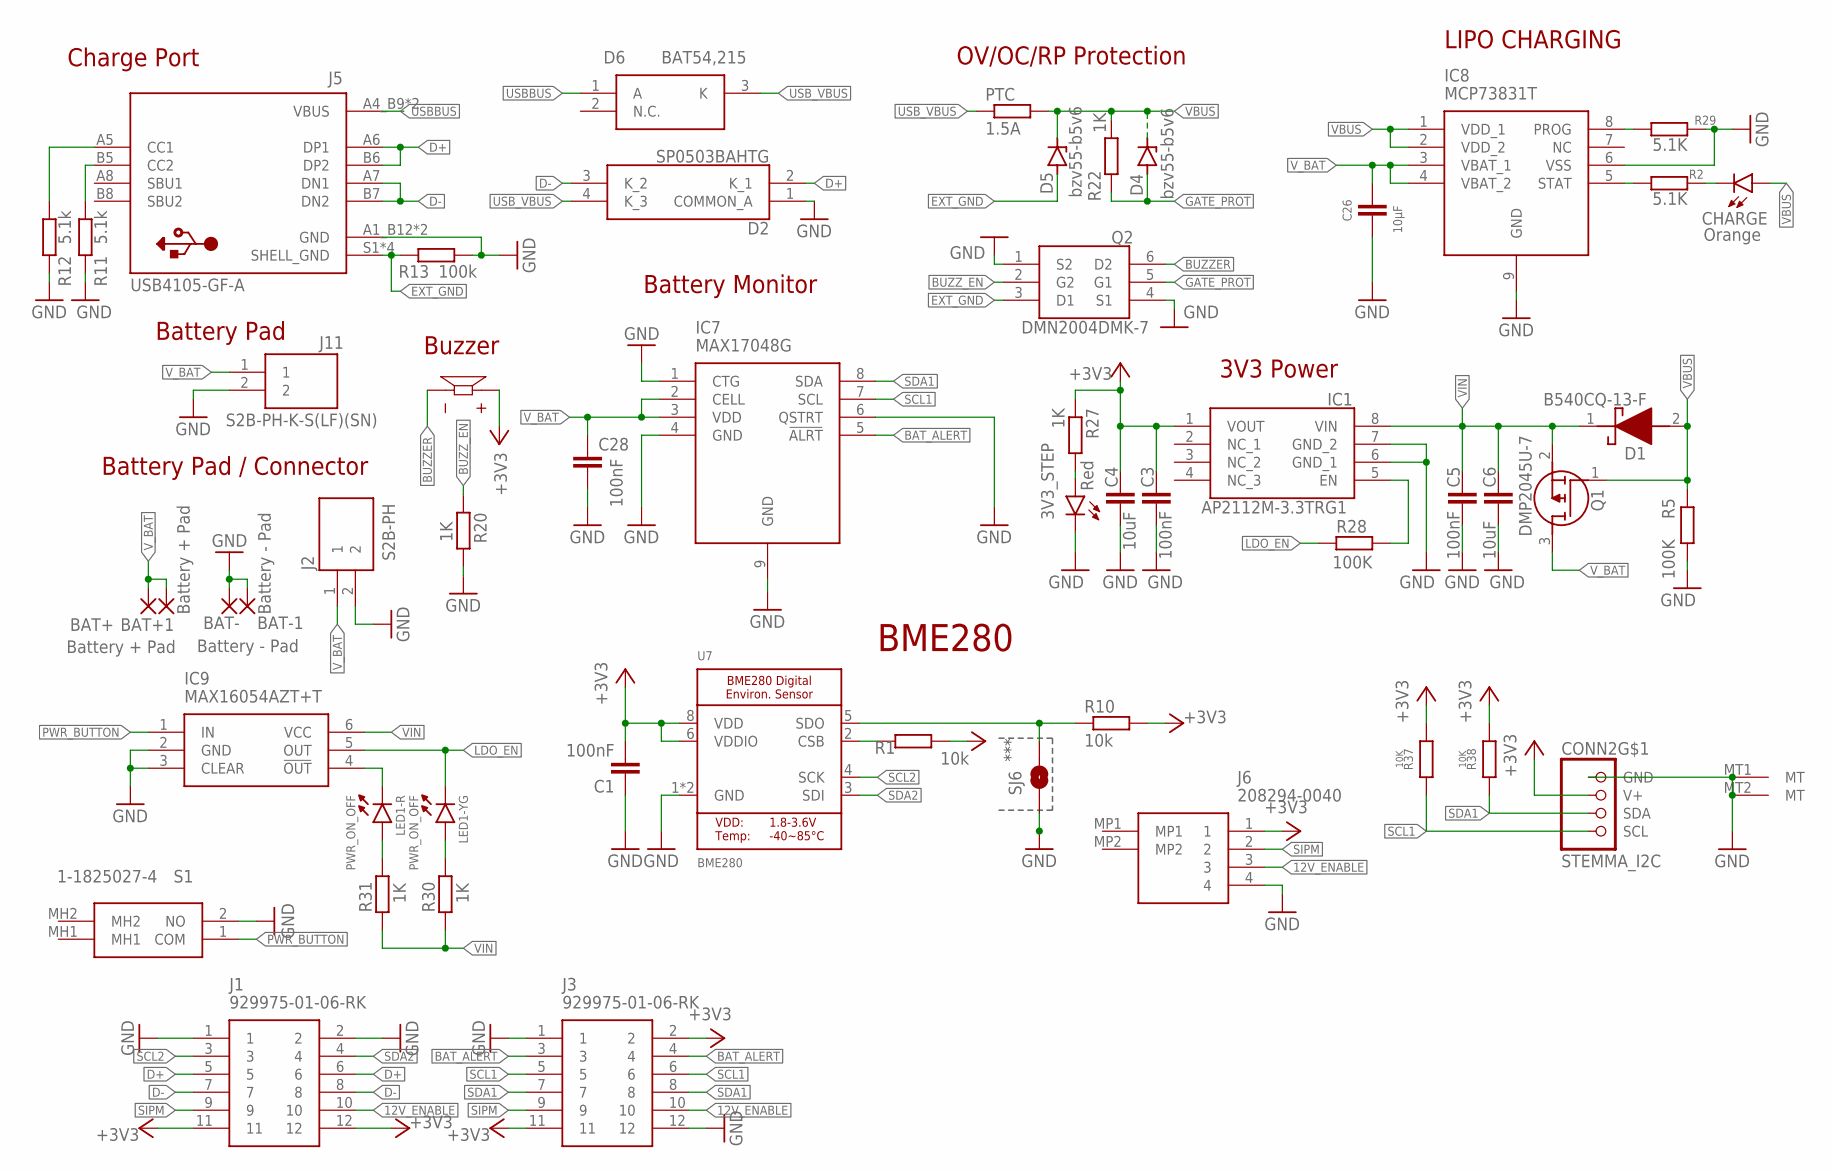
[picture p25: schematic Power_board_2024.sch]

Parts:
3V3_STEP: Red; CHIPLED_0805
BAT+, BAT+1: Battery + Pad; SMD2,54-5,08
BAT-, BAT-1: Battery - Pad; SMD2,54-5,08
BUZZER: CMI-1210-5-95T; XDCR_CMI-1210-5-95T
C1, C3, C5, C28: 100nF; C0603
C4, C6: 10uF; C0603
C26: 10µF; C0603
CHARGE: Orange; CHIPLED_0805
CONN2: STEMMA_I2C; JST_SH4
D1: B540CQ-13-F; DIOM7959X250N
D2: SP0503BAHTG
D4, D5: bzv55-b5v6; SOD80C
D6: BAT54,215; SOT95P230X110-3N
IC1: AP2112M-3.3TRG1; SOIC127P600X170-8N
IC7: MAX17048G; SON50P200X200X80-9N
IC8: MCP73831T; SON50P300X200X100-9N
IC9: MAX16054AZT+T; SOT95P275X110-6N
J1, J3: 929975-01-06-RK; RHDR12W76P254_2X6_1524X508X839
J2: S2B-PH; JST_S2B-PH-K-S(LF)(SN)
J5: USB4105-GF-A; GCT_USB4105-GF-A
J6: 208294-0040; 2082940040
J11: S2B-PH-K-S(LF)(SN); JST_S2B-PH-K-S(LF)(SN)
LED1: PWR_ON_OFF; 3216(1206)-4
PTC: 1.5A; R2512
Q1: DMP2045U-7; SOT96P240X110-3N
Q2: DMN2004DMK-7; SOT95P285X145-6N
R1, R10: 10k; R0603
R2, R29: 5.1K; R0603
R5, R28: 100K; R0603
R11, R12: 5.1k; R0603
R13: 100k; R0603
R20, R22, R27, R30, R31: 1K; R0603
R37, R38: 10K; R0603
S1: 1-1825027-4; 118250274
SJ6: SOLDER_JUMPER; SPARKFUN_SJ_2S-NO
U7: BME280

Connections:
12V_ENABLE: J1.10, J3.10, J6.3
+3V3: BUZZER.P, C1.2, C3.2, C4.2, CONN2.2 (V+), IC1.1 (VOUT), J1.11, J1.12, J3.2, J3.11, J6.1, R1.1, R10.2, R27.1, R37.2, R38.2, U7.6 (VDDIO), U7.8 (VDD)
BAT_ALERT: IC7.5 (!ALRT), J3.3, J3.4
BUZZER: BUZZER.N, Q2.6 (D2)
BUZZ_EN: Q2.2 (G2), R20.1
D+: D2.2 (K_1), J1.5, J1.6, J5.A6 (DP1), J5.B6 (DP2)
D-: D2.3 (K_2), J1.7, J1.8, J5.A7 (DN1), J5.B7 (DN2)
EXT_GND: D5.A, J5.S1 (SHELL_GND), J5.S2 (SHELL_GND), J5.S3 (SHELL_GND), J5.S4 (SHELL_GND), Q2.3 (D1), R13.2
FSYNC2: R10.1, SJ6.2, U7.5 (SDO)
GATE_PROT: D4.A, Q2.5 (G1), R22.1
GND: 3V3_STEP.C, BAT-.1, BAT-1.1, C1.1, C3.1, C4.1, C5.1, C6.1, C26.2, C28.2, CONN2.1 (GND), CONN2.MT1 (MT), CONN2.MT2 (MT), D2.1 (COMMON_A), IC1.6 (GND_1), IC1.7 (GND_2), IC7.1 (CTG), IC7.4 (GND), IC7.6 (QSTRT), IC7.9 (GND), IC8.6 (VSS), IC8.9 (GND), IC9.2 (GND), IC9.3 (CLEAR), J1.1, J1.2, J2.2, J3.1, J3.12, J5.A1_B12 (GND), J5.B1_A12 (GND), J6.4, J11.2, Q2.1 (S2), Q2.4 (S1), R5.2, R11.1, R12.1, R13.1, R20.2, R29.1, S1.2 (NO), SJ6.1, U7.1 (GND), U7.7 (GND)
LDO_EN: IC9.5 (OUT), LED1.3 (C), R28.1
unnamed: R1.2, U7.2 (CSB)
unnamed: IC8.5 (STAT), R2.2
unnamed: CHARGE.C, R2.1
unnamed: IC8.8 (PROG), R29.2
unnamed: IC9.4 (!OUT), LED1.1 (C)
unnamed: IC1.5 (EN), R28.2
unnamed: LED1.4 (A), R30.2
unnamed: LED1.2 (A), R31.2
unnamed: J5.B5 (CC2), R11.2
unnamed: J5.A5 (CC1), R12.2
unnamed: 3V3_STEP.A, R27.2
PWR_BUTTON: IC9.1 (IN), S1.1 (COM)
SCL1: CONN2.4 (SCL), IC7.7 (SCL), J3.5, J3.6, R37.1
SCL2: J1.3, U7.4 (SCK)
SDA1: CONN2.3 (SDA), IC7.8 (SDA), J3.7, J3.8, R38.1
SDA2: J1.4, U7.3 (SDI)
SIPM: J1.9, J3.9, J6.2
USBBUS: D6.1 (A), J5.A4_B9 (VBUS), J5.B4_A9 (VBUS)
USB_VBUS: D2.4 (K_3), D6.3 (K), PTC.1
VBUS: CHARGE.A, D1.2 (A), D4.C, D5.C, IC8.1 (VDD_1), IC8.2 (VDD_2), PTC.2, Q1.1 (G), R5.1, R22.2
VIN: C5.2, C6.2, D1.1 (K), IC1.8 (VIN), IC9.6 (VCC), Q1.2 (S), R30.1, R31.1
V_BAT: BAT+.1, BAT+1.1, C26.1, C28.1, IC7.2 (CELL), IC7.3 (VDD), IC8.3 (VBAT_1), IC8.4 (VBAT_2), J2.1, J11.1, Q1.3 (D)

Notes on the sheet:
Battery Pad
3V3 Power
Charge Port
Battery Pad / Connector
Buzzer
OV/OC/RP Protection
Battery Monitor
LIPO CHARGING
BME280
***

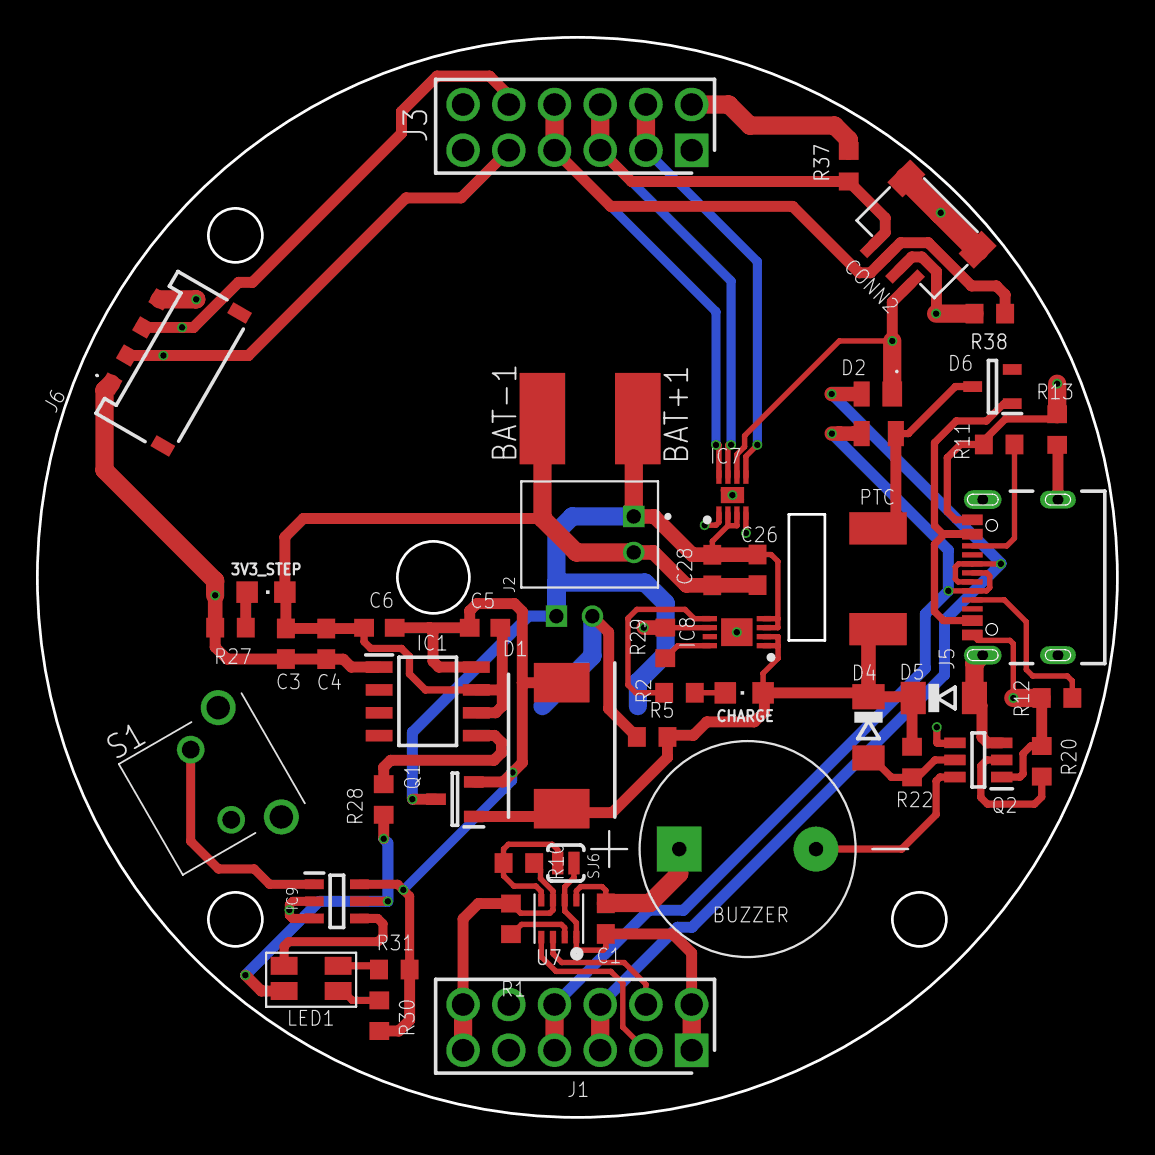
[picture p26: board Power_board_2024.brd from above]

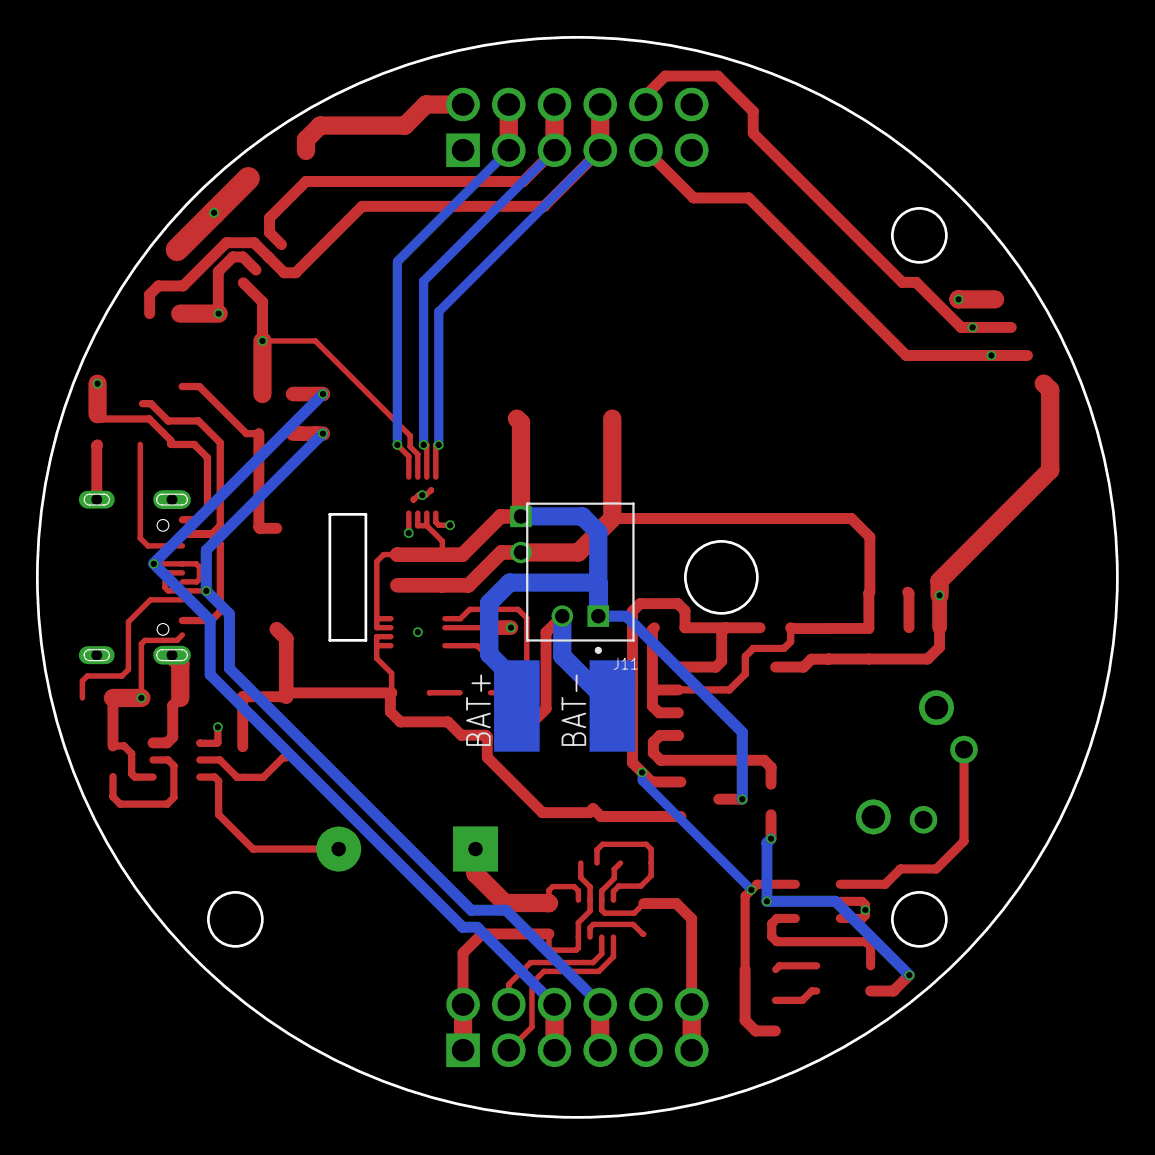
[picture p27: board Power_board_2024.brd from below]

Board: 4 copper layers, 60.0 x 60.0 mm, 53 parts (3 on the bottom side), 34 nets.

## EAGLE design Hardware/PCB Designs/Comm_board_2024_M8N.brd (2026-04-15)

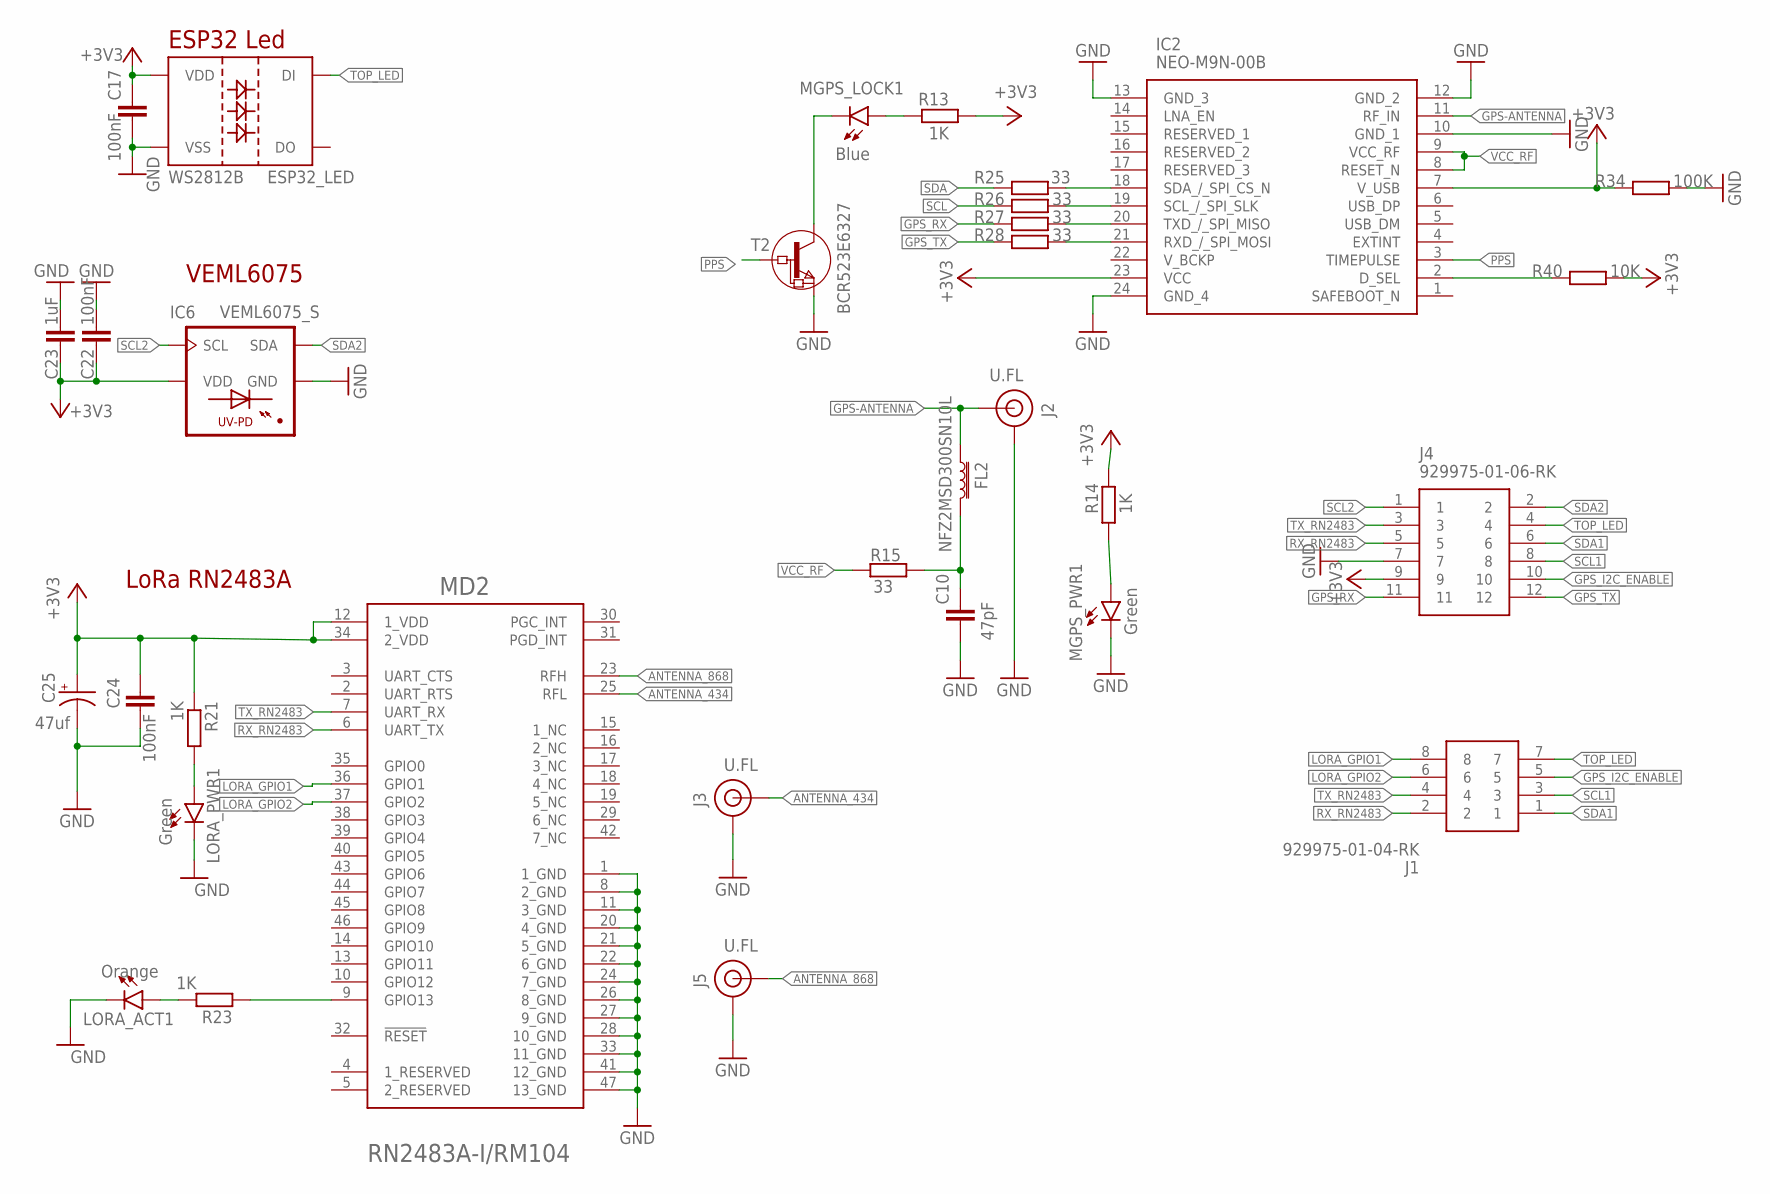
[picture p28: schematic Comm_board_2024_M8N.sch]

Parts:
C10: 47pF; C0603
C17, C22, C24: 100nF; C0603
C23: 1uF; C0603
C25: 47uf; CAPMP6032X250N
ESP32_LED: WS2812B
FL2: NFZ2MSD300SN10L; BEADC2016X120N
IC2: NEO-M9N-00B; NEOM9N00B
IC6: VEML6075_S; VISHAY_VEML6075_1.25X2X1
J1: 929975-01-04-RK; RHDR8W76P254_2X4_1016X508X839P
J2, J3, J5: U.FL; SPARKFUN-CONNECTORS_SPARKFUN-CONNECTORS_U.FL
J4: 929975-01-06-RK; RHDR12W76P254_2X6_1524X508X839
LORA_ACT1: Orange; CHIP-LED0603
LORA_PWR1: Green; CHIP-LED0603
MD2: RM104_MICROCHIP_RN2483A-I-RM104MICROCHIP_RN2483A-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; RM104_MICROCHIP_RN2483A-I-RM104_0
MGPS_LOCK1: Blue; CHIP-LED0603
MGPS_PWR1: Green; CHIP-LED0603
R13, R14, R21, R23: 1K; R0603
R15, R25, R26, R27, R28: 33; R0603
R34: 100K; R0603
R40: 10K; R0603
T2: BCR523E6327; SOT-23

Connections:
+3V3: C17.1, C22.2, C23.1, C24.1, C25.1 (+), ESP32_LED.1 (VDD), IC2.7 (V_USB), IC2.23 (VCC), IC6.4 (VDD), J4.9, MD2.12 (1_VDD), MD2.34 (2_VDD), R13.1, R14.2, R21.1, R34.2, R40.1
ANTENNA_434: J3.FEED (SIGNAL), MD2.25 (RFL)
ANTENNA_868: J5.FEED (SIGNAL), MD2.23 (RFH)
GND: C10.2, C17.2, C22.1, C23.2, C24.2, C25.2 (-), ESP32_LED.3 (VSS), IC2.10 (GND_1), IC2.12 (GND_2), IC2.13 (GND_3), IC2.24 (GND_4), IC6.1 (GND), J2.1 (GND), J2.2 (GND), J2.3 (GND), J3.1 (GND), J3.2 (GND), J3.3 (GND), J4.7, J5.1 (GND), J5.2 (GND), J5.3 (GND), LORA_ACT1.C, LORA_PWR1.C, MD2.1 (1_GND), MD2.8 (2_GND), MD2.11 (3_GND), MD2.20 (4_GND), MD2.21 (5_GND), MD2.22 (6_GND), MD2.24 (7_GND), MD2.26 (8_GND), MD2.27 (9_GND), MD2.28 (10_GND), MD2.33 (11_GND), MD2.41 (12_GND), MD2.47 (13_GND), MGPS_PWR1.C, R34.1, T2.2 (E)
GPS-ANTENNA: FL2.1 (3), IC2.11 (RF_IN), J2.FEED (SIGNAL)
GPS_I2C_ENABLE: J1.5, J4.10
GPS_RX: J4.11, R27.2
GPS_TX: J4.12, R28.2
LORA_GPIO1: J1.8, MD2.36 (GPIO1)
LORA_GPIO2: J1.6, MD2.37 (GPIO2)
unnamed: MGPS_LOCK1.A, R13.2
unnamed: MGPS_PWR1.A, R14.1
unnamed: IC2.20 (TXD_/_SPI_MISO), R27.1
unnamed: IC2.19 (SCL_/_SPI_SLK), R26.1
unnamed: IC2.18 (SDA_/_SPI_CS_N), R25.1
unnamed: IC2.21 (RXD_/_SPI_MOSI), R28.1
unnamed: IC2.2 (D_SEL), R40.2
unnamed: MGPS_LOCK1.C, T2.1 (C)
unnamed: C10.1, FL2.2 (4), R15.1
unnamed: MD2.9 (GPIO13), R23.1
unnamed: LORA_ACT1.A, R23.2
unnamed: LORA_PWR1.A, R21.2
PPS: IC2.3 (TIMEPULSE), T2.3 (B)
RX_RN2483: J1.2, J4.5, MD2.6 (UART_TX)
SCL: R26.2
SCL1: J1.3, J4.8
SCL2: IC6.3 (SCL), J4.1
SDA: R25.2
SDA1: J1.1, J4.6
SDA2: IC6.2 (SDA), J4.2
TOP_LED: ESP32_LED.4 (DI), J1.7, J4.4
TX_RN2483: J1.4, J4.3, MD2.7 (UART_RX)
VCC_RF: IC2.8 (RESET_N), IC2.9 (VCC_RF), R15.2

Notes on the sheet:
ESP32 Led
VEML6075
LoRa RN2483A

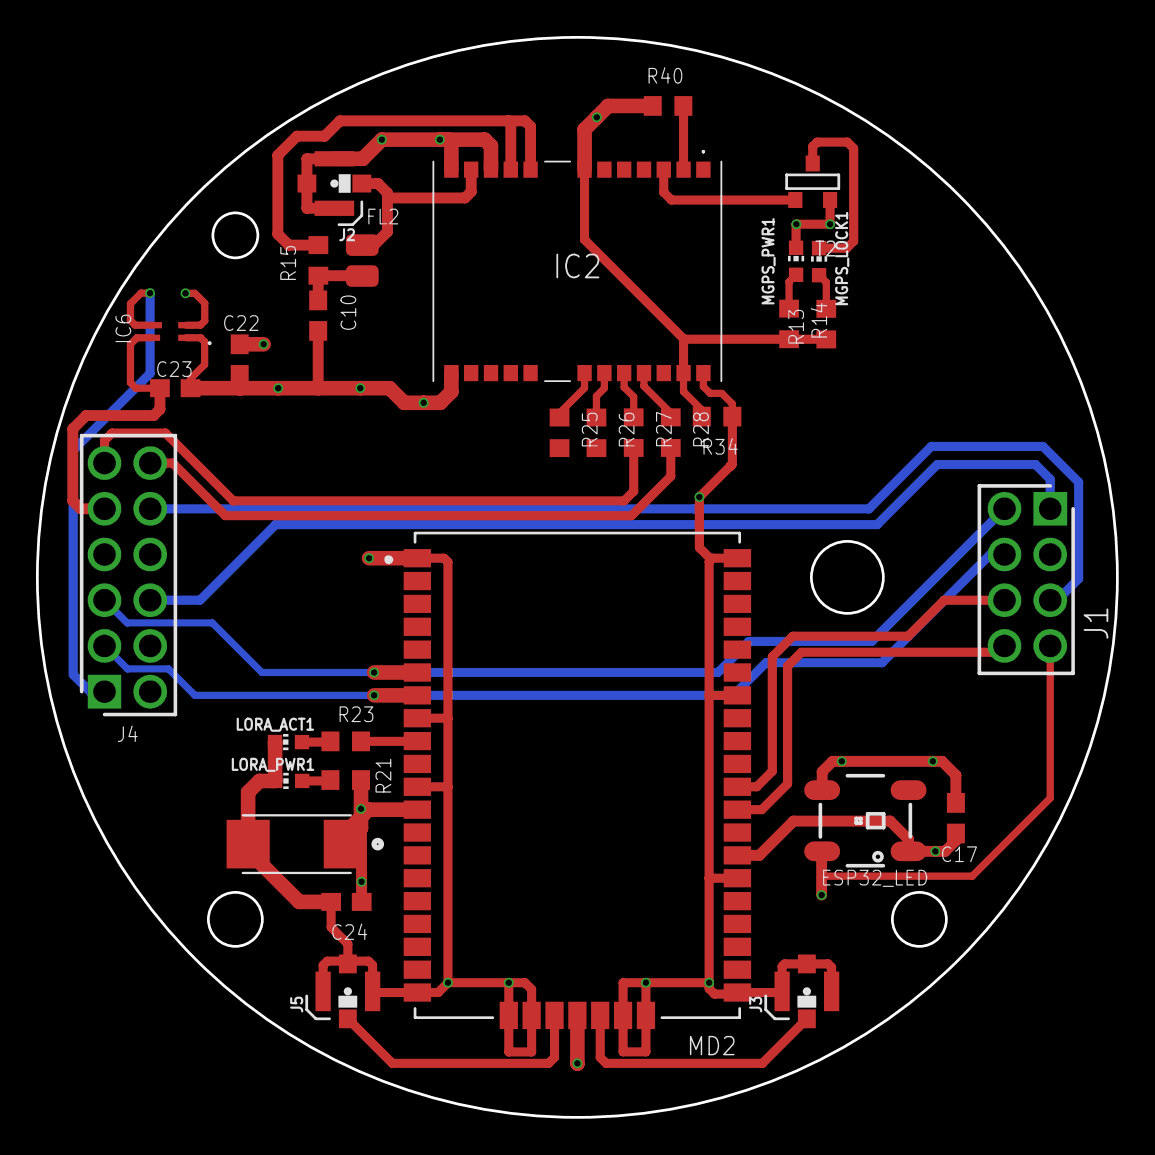
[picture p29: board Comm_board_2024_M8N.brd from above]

Board: 4 copper layers, 60.0 x 60.0 mm, 32 parts (0 on the bottom side), 31 nets.

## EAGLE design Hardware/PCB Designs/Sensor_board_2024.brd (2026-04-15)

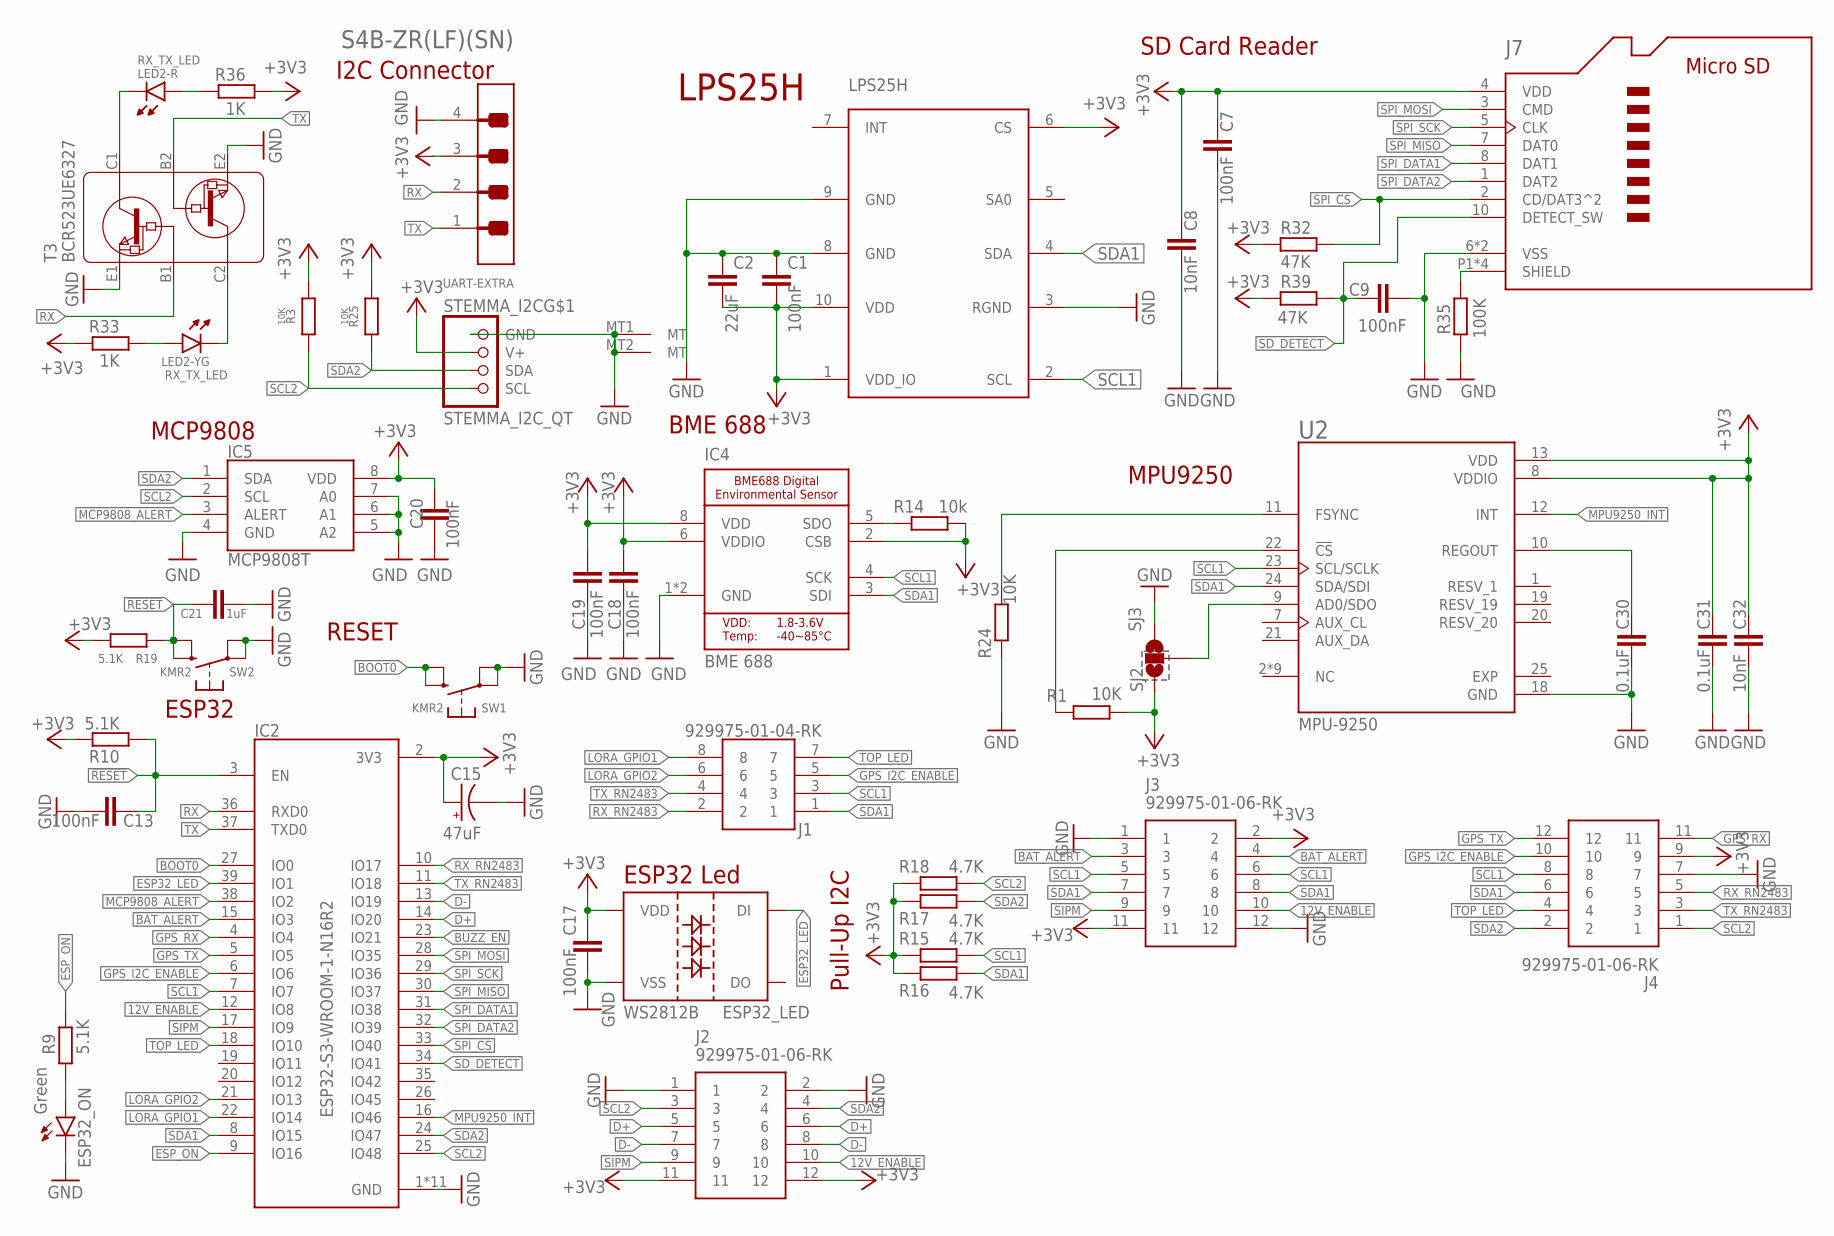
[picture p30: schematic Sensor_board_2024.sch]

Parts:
C1, C7, C9, C13, C17, C18, C19, C20: 100nF; C0603
C2: 22uF; C0603
C8: 10nF; C0603
C15: 47uF; CAPMP6032X250N
C21: 1uF; C0603
C30, C31: 0.1uF; 0603-CAP
C32: 10nF; 0603-CAP
ESP32_LED: WS2812B
ESP32_ON: Green; CHIPLED_0805
IC2: ESP32-S3-WROOM-1-N16R2; XCVR_ESP32-S3-WROOM-1-N16R2
IC4: BME 688; BME_688
IC5: MCP9808T; SOP65P490X110-8N
J1: 929975-01-04-RK; RHDR8W76P254_2X4_1016X508X839P
J2, J3, J4: 929975-01-06-RK; RHDR12W76P254_2X6_1524X508X839
J7: 503398-1892; MOLEX_503398-1892
LED2: RX_TX_LED; 3216(1206)-4
LPS25H: LPS25H
R1, R3, R24, R25: 10K; R0603
R9, R10, R19: 5.1K; R0603
R14: 10k; R0603
R15, R16, R17, R18: 4.7K; R0603
R32, R39: 47K; R0603
R33, R36: 1K; R0603
R35: 100K; R0603
SJ2: SJ3; SPARKFUN_SJ_3
STEMMA_I2C: STEMMA_I2C_QT; JST_SH4
SW1, SW2: KMR2; BTN_KMR2_4.6X2.8
T3: BCR523UE6327; SOT-23
U2: MPU-9250; QFN40P300X300X105-25N
UART-EXTRA: JST_S4B-ZR_LF; JST_S4B-ZR_LF_SN_0

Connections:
12V_ENABLE: IC2.12 (IO8), J2.10, J3.10
!RESET: C13.1, C21.1, IC2.3 (EN), R10.1, R19.1, SW2.B (S), SW2.B' (S1)
+3V3: C1.2, C2.2, C7.1, C8.1, C15.1 (+), C17.1, C18.2, C19.2, C20.2, C31.1, C32.1, ESP32_LED.1 (VDD), IC2.2 (3V3), IC4.2 (CSB), IC4.6 (VDDIO), IC4.8 (VDD), IC5.8 (VDD), J2.11, J2.12, J3.2, J3.11, J4.9, J7.4 (VDD), LPS25H.1 (VDD_IO), LPS25H.6 (CS), LPS25H.10 (VDD), R1.2, R3.2, R10.2, R14.2, R15.2, R16.2, R17.2, R18.2, R19.2, R25.2, R32.2, R33.2, R36.1, R39.2, SJ2.1, STEMMA_I2C.2 (V+), U2.8 (VDDIO), U2.13 (VDD), UART-EXTRA.3
BAT_ALERT: IC2.15 (IO3), J3.3, J3.4
BOOT0: IC2.27 (IO0), SW1.B (S), SW1.B' (S1)
BUZZ_EN: IC2.23 (IO21)
D+: IC2.14 (IO20), J2.5, J2.6
D-: IC2.13 (IO19), J2.7, J2.8
ESP32_LED: ESP32_LED.4 (DI), IC2.39 (IO1)
ESP_ON: IC2.9 (IO16), R9.2
GND: C1.1, C2.1, C7.2, C8.2, C9.2, C13.2, C15.2 (-), C17.2, C18.1, C19.1, C20.1, C21.2, C30.2, C31.2, C32.2, ESP32_LED.3 (VSS), ESP32_ON.C, IC2.1 (GND), IC2.40 (GND), IC2.41_1 (GND), IC2.41_2 (GND), IC2.41_3 (GND), IC2.41_4 (GND), IC2.41_5 (GND), IC2.41_6 (GND), IC2.41_7 (GND), IC2.41_8 (GND), IC2.41_9 (GND), IC4.1 (GND), IC4.7 (GND), IC5.4 (GND), IC5.5 (A2), IC5.6 (A1), IC5.7 (A0), J2.1, J2.2, J3.1, J3.12, J4.7, J7.6 (VSS), J7.9 (VSS), LPS25H.3 (RGND), LPS25H.8 (GND), LPS25H.9 (GND), R24.1, R35.1, SJ2.3, STEMMA_I2C.1 (GND), STEMMA_I2C.MT1 (MT), STEMMA_I2C.MT2 (MT), SW1.A, SW1.A' (P1), SW2.A, SW2.A' (P1), T3.E1, T3.E2, U2.18 (GND), UART-EXTRA.4
GPS_I2C_ENABLE: IC2.6 (IO6), J1.5, J4.10
GPS_RX: IC2.4 (IO4), J4.11
GPS_TX: IC2.5 (IO5), J4.12
LORA_GPIO1: IC2.22 (IO14), J1.8
LORA_GPIO2: IC2.21 (IO13), J1.6
MCP9808_ALERT: IC2.38 (IO2), IC5.3 (ALERT)
MICROSD_SH2: J7.P1 (SHIELD), J7.P2 (SHIELD), J7.P3 (SHIELD), J7.P4 (SHIELD), R35.2
MPU9250_INT: IC2.16 (IO46), U2.12 (INT)
unnamed: IC4.5 (SDO), R14.1
unnamed: R1.1, U2.22 (!CS)
unnamed: R24.2, U2.11 (FSYNC)
unnamed: ESP32_ON.A, R9.1
unnamed: SJ2.2, U2.9 (AD0/SDO)
unnamed: LED2.3 (C), T3.C2
unnamed: LED2.1 (C), T3.C1
unnamed: LED2.2 (A), R36.2
unnamed: LED2.4 (A), R33.1
REGOUT: C30.1, U2.10 (REGOUT)
RESV_1: U2.1 (RESV_1)
RESV_20: U2.20 (RESV_20)
RX: IC2.36 (RXD0), T3.B1, UART-EXTRA.2
RX_RN2483: IC2.10 (IO17), J1.2, J4.5
SCL1: IC2.7 (IO7), IC4.4 (SCK), J1.3, J3.5, J3.6, J4.8, LPS25H.2 (SCL), R15.1, U2.23 (SCL/SCLK)
SCL2: IC2.25 (IO48), IC5.2 (SCL), J2.3, J4.1, R3.1, R18.1, STEMMA_I2C.4 (SCL)
SDA1: IC2.8 (IO15), IC4.3 (SDI), J1.1, J3.7, J3.8, J4.6, LPS25H.4 (SDA), R16.1, U2.24 (SDA/SDI)
SDA2: IC2.24 (IO47), IC5.1 (SDA), J2.4, J4.2, R17.1, R25.1, STEMMA_I2C.3 (SDA)
SD_DETECT: C9.1, IC2.34 (IO41), J7.10 (DETECT_SW), R39.1
SIPM: IC2.17 (IO9), J2.9, J3.9
SPI_CS: IC2.33 (IO40), J7.2 (CD/DAT3^2), R32.1
SPI_DATA1: IC2.31 (IO38), J7.8 (DAT1)
SPI_DATA2: IC2.32 (IO39), J7.1 (DAT2)
SPI_MISO: IC2.30 (IO37), J7.7 (DAT0)
SPI_MOSI: IC2.28 (IO35), J7.3 (CMD)
SPI_SCK: IC2.29 (IO36), J7.5 (CLK)
TOP_LED: IC2.18 (IO10), J1.7, J4.4
TX: IC2.37 (TXD0), T3.B2, UART-EXTRA.1
TX_RN2483: IC2.11 (IO18), J1.4, J4.3

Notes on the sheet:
ESP32
SD Card Reader
ESP32 Led
BME 688
MCP9808
Pull-Up I2C
RESET
LPS25H
MPU9250
I2C Connector

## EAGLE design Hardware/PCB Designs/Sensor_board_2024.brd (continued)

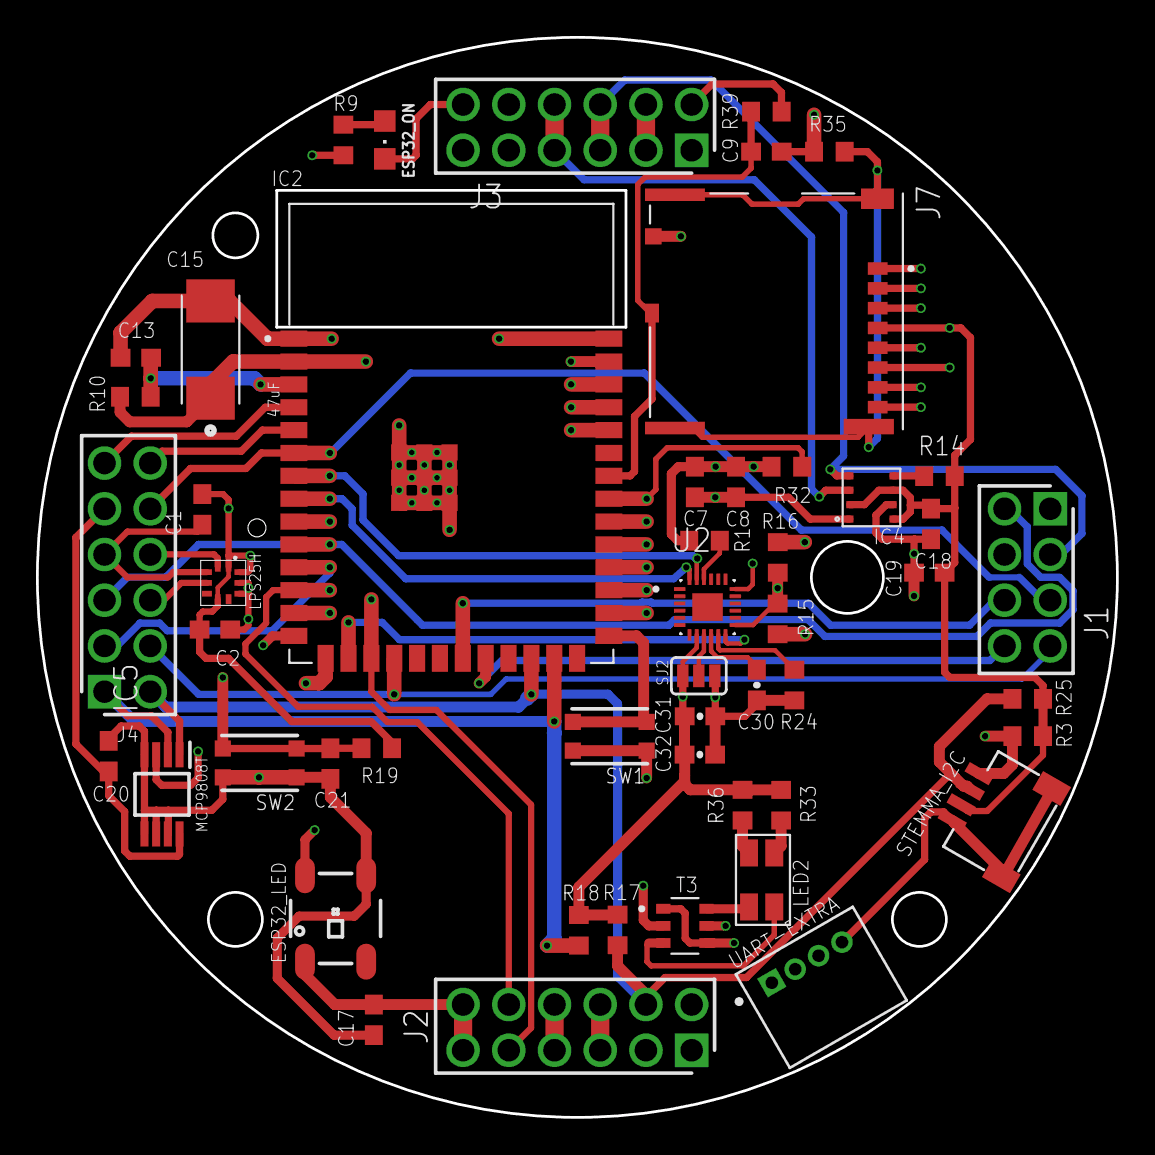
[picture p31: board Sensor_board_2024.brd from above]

Board: 4 copper layers, 60.0 x 60.0 mm, 51 parts (0 on the bottom side), 45 nets.

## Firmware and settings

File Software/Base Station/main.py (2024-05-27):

from network import LoRa
import socket
import ujson
import pycom
import time
import utime
from machine import SD, RTC
import os
import gc
from network import WLAN
from logger import Logger
from converters import timeConverter, localtime_to_epoch
from utils import generate_random_filename


# Constants
LoRa_freq = 868000000  # frequency in Hz
SDDir = 'BaseSD'
switch = True

# The provided KEY_MAP
KEY_MAP = {
    "pid": "pid",
    "type": "type",
    "epochtime": "etm",
    "valid": "vld",
    "esp32": "e32",
    "wifi_signal_strength": "wss",
    "free_memory": "fm",
    "altitude": "alt",
    "temperature": "tmp",
    "bmp280": "b28",
    "lps25h": "l25",
    "lis3mdl": "l3m",
    "pressure": "prs",
    "acceleration": "acc",
    "gyroscope": "gyr",
    "gps_coordinates": "gps",
    "air_quality": "aq",
    "ccs811": "c81",
    "eCO2": "eco",
    "tVOC": "tvoc",
    "telemetry": "tlm",
    "mpu9250": "mpu",
    "accel_x": "a_x",
    "accel_y": "a_y",
    "accel_z": "a_z",
    "gyro_x": "g_x",
    "gyro_y": "g_y",
    "gyro_z": "g_z",
    "mag_x": "m_x",
    "mag_y": "m_y",
    "mag_z": "m_z",
    "longitude": "lon",
    "latitude": "lat",
    "speed": "spd",
    "timestamp": "tmsp",
    "magnetic_variation": "mv",
    "course": "crs",
    "null": "na",
    "pres": "pre",
    "temp": "tme"
}

packets = {}
packet_count = {}
last_pid = None 

pycom.heartbeat(False)  # Disable the heartbeat LED
pycom.rgbled(0xFFFF00)
time.sleep(0.5)

try:
    print("\n"+60*"-"+"\nStarting initialization process...\n"+60*"-"+"\n")
    # disable LED heartbeat (so we can control the LED)
    pycom.heartbeat(False)
    # set LED to red
    pycom.rgbled(0x110000)

    # Reverse the KEY_MAP dictionary
    REVERSED_KEY_MAP = {v: k for k, v in KEY_MAP.items()}

    # Mount SD Card
    try:
        sd = SD()
        os.mount(sd, '/' + SDDir)
        print (" [  OK  ] SD Card mounted as '/{}'".format(SDDir)) 
    except Exception as e:
        print (" [ FAIL ] SD Card not mounted")
        pycom.rgbled(0xFFFF00)  # Yellow light if failed


    # Initialize LoRa
    try:
        lora = LoRa(mode=LoRa.LORA, 
                        frequency=LoRa_freq, 
                        region=LoRa.EU868, 
                        bandwidth=LoRa.BW_125KHZ, 
                        sf=7, 
                        coding_rate=LoRa.CODING_4_5, 
                        power_mode=LoRa.ALWAYS_ON, 
                        rx_iq=False, 
                        public=False)
        s = socket.socket(socket.AF_LORA, socket.SOCK_RAW)
        s.setblocking(False)  # Non-blocking mode
        print(" [  OK  ] LoRa Initialized on {0:3.2f} MHz".format(LoRa_freq/1000000))  # Green light if LoRa initialized successfully
        pycom.rgbled(0x000011)
    except Exception as e:
        print(" [ FAIL ] LoRa initialization failed:", str(e))
        pycom.rgbled(0xFF0000)

    try:
        rtc = RTC()
        rtc.ntp_sync("pool.ntp.org")
        if not rtc.synced():
            rtc_on = False
            current_time = generate_random_filename()
        else:
            current_time = timeConverter(utime.localtime())
            rtc_on = True
        utime.sleep_ms(750)
        utime.timezone(7200)
        rtc_msg_log_ok = " [  OK  ] RTC Set from NTP\n"+14*" "+"EST timezone: {}".format(timeConverter(utime.localtime()))
        print (rtc_msg_log_ok)
    except Exception as e:
        rtc_msg_log_fail = " [ FAIL ] RTC raised an exception {}".format(e)
        rtc_on = False
        print (rtc_msg_log_fail)  

    try:
        if rtc_on:
            filename="{}_log".format(localtime_to_epoch(utime.localtime()))
        else:
            filename=generate_random_filename()
        wd = 'CanSat2024Data/'+ filename
        logger = Logger(workingDirectory = wd, daytime=utime.time())
        currentDir, currentLog = logger.files_setup(subdir=filename)
        print (" [  OK  ] Logger started on:\n"+14*" "+"{}".format(currentDir))
    except Exception as e:
        print (" [ FAIL ] Logger offline (error: {})".format(e)) 

except Exception as e:
    print("\n----------------------------------\nInitialization failed...\n----------------------------------\n")
    switch = False
    pycom.heartbeat(False)
    pycom.rgbled(0xffa500)

# print("Logs saved in {}".format(currentLog))
empty_dict={}
# print(currentLog)
with open(currentLog, 'w') as fp:
    ujson.dump(empty_dict, fp)

# Dictionary to hold the received parts of JSON packets
packets = {}

# global last_pid
# last_pid=1

def check_internet_and_sync_time():
    wlan = WLAN(mode=WLAN.STA)
    wlan.connect('CDOSR', auth=(WLAN.WPA2, 'c4ns4t2024'), timeout=5000)

    while not wlan.isconnected():  # Check if the connection was successful
        utime.sleep(0.25)
    if wlan.isconnected():
        print("Internet connected, syncing time...")
        # Sync time using NTP server; actual implementation depends on your device libraries
        # Assuming RTC is set up properly here and connected to NTP
        return True
    else:
        print("Failed to connect to the internet.")
        return False

def append_to_json(filelog, packet):
    # Ensure directory exists before opening a file
    try:
        # Open the file in read mode to check if it exists and has contents
        with open(filelog, 'r') as f:
            file_data = ujson.load(f)
    except FileNotFoundError:
        # If the file does not exist, initialize an empty dictionary
        file_data = {}

    # Update the file data with new packet data
    file_data.update({str(packet['pid']): packet})

    # Write the updated data back to the file
    try:
        with open(filelog, 'w') as f:
            ujson.dump(file_data, f)
            pycom.rgbled(0xFF00FF)
            print("Successfully updated {}".format(filelog))
    
    finally:
        # Optionally, reset the LED color or turn it off after a delay
        time.sleep(0.05)
        pycom.rgbled(0x000000) 

def process_packet(packet_data):
    global packets, packet_count, last_pid  # Ensure that packets is accessible and can maintain state across function calls
    try:
        # Decode bytes to string and adjust the JSON formatting
        formatted_data = packet_data.decode('utf-8').strip('b"\'').replace("'", '"')
        new_data = formatted_data.replace("\\", "")

        # Load the JSON data
        packet = ujson.loads(new_data)
        pid = packet['pid']

        # Initialize the storage for this pid if it does not exist
        if pid not in packets:
            packets[pid] = {}
            packet_count[pid] = 0

        # Merge new data into the existing structure for this PID
        packet_count[pid] += 1
        packets[pid] = merge_dicts(packet, packets[pid])

        # Temporary: Print the merged data to verify
        # print("Merged data for PID {}: {}".format(pid, packets[pid]))

        # # Update the packet data by merging it properly
        # merge_packet_data(packets[pid], packet)
        # print("Formatted data: " + ujson.dumps(packet))

        # Check if all required parts of the message have been received
        if packet_count[pid] == 4 or (last_pid is not None and pid != last_pid):
            if is_complete(packets[pid]):
                complete_data = packets.pop(pid)
                packet_count.pop(pid)
                # print("Complete data received for PID {}: {}".format(pid, ujson.dumps(complete_data)))
                return complete_data
            else:
                print("Data for PID {} is incomplete, awaiting more data.".format(pid))
        else:
            print("Awaiting more data for PID {}".format(pid))

        last_pid = pid  # Update last processed PID

    except Exception as e:
        print("Failed to process packet:", str(e))

def merge_dicts(source, destination):
    """
    Recursively merge dictionaries. 
    Update destination dictionary with values from the source dictionary.
    """
    for key, value in source.items():
        if isinstance(value, dict):
            # Get node or create one
            node = destination.setdefault(key, {})
            merge_dicts(value, node)
        else:
            destination[key] = value

    return destination

def merge_packet_data(existing_data, new_data):
    """Recursively merge new data into existing dictionary without overwriting."""
    for key, value in new_data.items():
        if key in existing_data and isinstance(existing_data[key], dict) and isinstance(value, dict):
            merge_packet_data(existing_data[key], value)
        else:
            existing_data[key] = value

def is_complete(data):
    """Determine if all required parts of the message have been received."""
    # Example check for required fields
    # required_fields = ['gps', 'temperature', 'pressure', 'humidity']  # Adjust based on actual requirements
    # return all(field in packet for field in required_fields)
    required_keys = ['gps', 'bat', 'tme', 'hum', 'alt', 'acc', 'gyro']  # Example
    return all(key in data for key in required_keys)


def receive_packets(filename):
    while True:
        try:
            s.setblocking(True)
            packet = s.recv(1024)  # Adjust based on expected maximum packet size
            if packet:
                pycom.rgbled(0xFFFF00) 
                #print(process_packet(packet_data=packet))
                complete_packet=process_packet(packet)
                if complete_packet is not None:
                    renamed_packet = {REVERSED_KEY_MAP.get(key, key): value for key, value in complete_packet.items()}
                    # print(ujson.dumps(renamed_packet))
                    append_to_json(filename, renamed_packet)
                    # with open('result.json', 'w') as fp:
                    #     ujson.dump(renamed_packet, fp)
                pycom.rgbled(0xFF00FF)  # Magenta LED indicates data processing
            else:
                print("No packet received")
        except socket.timeout:
            print("Socket timeout, no packet received")
            pycom.rgbled(0xFF0000)
        except Exception as e:
            print("Error receiving packet:", str(e))
            pycom.rgbled(0xFF0000) 
        time.sleep(0.25)

gc.enable()
receive_packets(currentLog)

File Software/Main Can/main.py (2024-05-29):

# Import necessary modules
from sensors.accelerometer import ICM20948
from sensors.pressure import LPS25H, BME688
from sensors.air_quality import AirQualitySensor
from sensors.temperature import TemperatureSensor, MCP9808, BME280
from sensors.uv_sensor import VEML6075
from sensors.gps import M8NNeo
from communications.bluetooth import BluetoothComm
from communications.lora import LoRaComm
from storage.sdcard import SDCard
from sensors.battery import MAX17048
from sensors.esp import ESP32Data
from machine import deepsleep, Pin
import cansat
import utime
import ntptime
from machine import RTC, Pin, UART, I2C
import network
import time
from config import WIFI_CREDENTIALS, KEY_MAP # Import your Wi-Fi credentials list
from communications.ntp import get_epoch_time, get_formatted_localtime
from communications.dataintegrity import get_data_checksum
from sensors.sensor_manager import SensorManager
from utils.logger import Logger
import json
import os
from utils.neopixel import NeoPixelControl
from utils.datalogger import DataLogger
from utils.buzzer import activate_buzzer, deactivate_buzzer, test_buzzer

# Configuration settings
# import config

sensor_data = {
    'epoch': None,
    'local': None,
    'pid': None,
    'data': {
        'alt': None, #altitude
        'acc': None, #acceleration
        'pres': None, #pressure
        'hum':  None, #humidity
        'gyro': None, #gyroscope
        'mag': None, #magnetometric
        'temp': None, #temperature
        'uv': None, #uv_index
        'air': None, #air_quality
        'gps': None, #gps_coordinates
        'bat': None # battery_level
    },
    'esp32': {
        'fmem': None, #free_memory
        'wss': None #wifi_signal_strength
    }
}

#buzzer = buzzer = Pin(21, Pin.OUT)

np_controller = NeoPixelControl(pin_number=10, num_pixels=1)
np_controller.clear()
np_controller.set_pixel(1,255,255,0)

# test_buzzer(1)

# Instantiate the loggers
log = Logger()
dlog = DataLogger()
#sd_card = SDCard(2, 40)

def initialize_system():
    """Initialize all system components including sensors and communication modules."""
    global altimeter, accelerometer, mems_module, air_quality_sensor, temperature_sensor, uv_sensor, gps_sensor, battery, bluetooth_comm, lora_comm, sd_card, esp32#, temperature_2
    log.log_event("INFO", "Sensor initialisation started", running="main.py", function="initialize_system()")
    
    try:
        accelerometer = ICM20948()
        # print(f"ICM20948 initialised done on I2C{ICM20948().channel}")
        log.log_event("INFO", f"ICM20948 initialised done on I2C{ICM20948().channel}", running="main.py", function="initialize_system()", module="ICM20948")
    except Exception as e:
        log.log_event("ERROR", "ICM20948 not initialised", running="main.py", function="initialize_system()", module="ICM20948")

    try:
        pressure = LPS25H()
        # print(f"ICM20948 initialised done on I2C{ICM20948().channel}")
        log.log_event("INFO", f"LPS25H initialised done on I2C{LPS25H().channel}", running="main.py", function="initialize_system()", module="LPS25H")
    except Exception as e:
        log.log_event("ERROR", "ICM20948 not initialised", running="main.py", function="initialize_system()", module="LPS25H", error=e)

    try:
        temperature_1 = MCP9808()
        # print(f"ICM20948 initialised done on I2C{ICM20948().channel}")
        log.log_event("INFO", f"MCP9808 initialised done on I2C{MCP9808().channel}", running="main.py", function="initialize_system()", module="MCP9808")
    except Exception as e:
        log.log_event("ERROR", "MCP9808 not initialised", running="main.py", function="initialize_system()", module="MCP9808", error=e)

    try:
        pressure2 = BME688()
        # print(f"ICM20948 initialised done on I2C{ICM20948().channel}")
        log.log_event("INFO", f"BME688 initialised done on I2C{BME688().channel}", running="main.py", function="initialize_system()", module="BME688")
    except Exception as e:
        log.log_event("ERROR", "BME688 not initialised", running="main.py", function="initialize_system()", module="BME688", error=e)

    try:
        temperature_2 = BME280()
        # print(f"ICM20948 initialised done on I2C{ICM20948().channel}")
        log.log_event("INFO", f"BME280 initialised done on I2C{BME280().channel}", running="main.py", function="initialize_system()", module="BME280")
    except Exception as e:
        log.log_event("ERROR", "BME280 not initialised", running="main.py", function="initialize_system()", module="BME280", error=e)
#     print(f"    BME280 initialised done on I2C{MCP9808().channel}")
    
    try:
        uv_sensor = VEML6075()
        log.log_event("INFO", f"VEML6075 initialised done on I2C{VEML6075().channel}", running="main.py", function="initialize_system()", module="VEML6075")
    except Exception as e:
        log.log_event("ERROR", "VEML6075 not initialised", running="main.py", function="initialize_system()", module="VEML6075", error=e)

    try:
        battery = MAX17048()
        log.log_event("INFO", f"MAX17048 initialised done on I2C{MAX17048().channel}", running="main.py", function="initialize_system()", module="MAX17048")
    except Exception as e:
        log.log_event("ERROR", "MAX17048 not initialised", running="main.py", function="initialize_system()", module="MAX17048", error=e)

    try:
        gps_sensor = M8NNeo()
        log.log_event("INFO", f"M8N-NEO initialised done on UART{M8NNeo().channel}", running="main.py", function="initialize_system()", module="M8N-NEO")
    except Exception as e:
        log.log_event("ERROR", "M8N-NEO not initialised", running="main.py", function="initialize_system()", module="M8N-NEO", error=e)

    try:
        esp32 = ESP32Data()
        log.log_event("INFO", f"ESP32Data initialised done", running="main.py", function="initialize_system()", module="ESP32Data")
    except Exception as e:
        log.log_event("ERROR", "ESP32Data not initialised", running="main.py", function="initialize_system()", module="ESP32Data")

    print("  + Sensors initialized successfully.")
    log.log_event("INFO", "Sensors initialized successfully.")
    
    try:
        bluetooth_comm = BluetoothComm()
    except Exception as e:
        print(f"Bluetooth init error {e}")
    
    try:
        lora_comm = LoRaComm()
    except Exception as e:
        print(f"Lora init error {e}")
#     print("...sdcard 1...")
#     sd_card = SDCard(spi_bus=1, cs_pin=40)
#     print("...sdcard 2...")
    
    print(" + System initialized successfully.")
    np_controller.clear()
    np_controller.set_pixel(1,0,255,0)



# Example usage of the logger
log.log_event("INFO", "Starting system initialization", running="main.py")
# logger.log("Debugging sensor connectivity", "DEBUG")

def format_filename(base_filename, counter):
    # Create a formatted string with leading zeros, assuming no more than 999 files
    filename = "{}_{:03}.json".format(base_filename, counter)
    return filename
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

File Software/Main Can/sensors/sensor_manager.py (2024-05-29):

# Import necessary modules
# from sensors.altimeter import Altimeter
from sensors.accelerometer import ICM20948 #MPU9250
from sensors.pressure import LPS25H, BME688
# from sensors.mems_module import LIS3MDL
# from sensors.air_quality import AirQualitySensor, CCS811
from sensors.temperature import MCP9808, BME280
from sensors.uv_sensor import VEML6075
from sensors.gps import M8NNeo
from communications.bluetooth import BluetoothComm
from communications.lora import LoRaComm
from storage.sdcard import SDCard
from sensors.battery import MAX17048 
from sensors.esp import ESP32Data
from utils.logger import Logger

log = Logger()

class SensorManager:
    def __init__(self):
        self.initialize_sensors()

    def initialize_sensors(self):
        """Initialize or reinitialize all sensor objects."""
        self.accelerometer1 = ICM20948()
        self.pressure1 = LPS25H()
        self.pressure2 = BME688()
        self.pressure1.enableLPS()
        self.magnetometric1 = ICM20948()
        self.temperature1 = MCP9808()
        self.temperature2 = BME280()
        self.uv_sensor = VEML6075()
        self.gps_sensor = M8NNeo()
        self.battery = MAX17048()
        
    def log_error(self, sensor_name, error):
        log.log_event("ERROR", f"Error reading {sensor_name}", running="sensor_manager.py", function="collect_data()", error=f"{error}")
        print(f"Error reading {sensor_name}: {error}")

    def collect_data(self):
        """Collect data from all sensors, handling exceptions individually."""
        data = {
            'alt': {}, #altitude
            'acc': {}, #acceleration
            'pres': {}, #pressure
            'temp': {}, #temperature
            'hum' : {}, #humidity
            'gyro': {}, #gyroscope
            'mag': {}, #magnetometric
            'uv': {}, #uv_index
            'air': {}, #air_quality
            'gps': {}, #gps_coordinates
            'bat': {} #battery_level
        }
        radiodata = {
            'alt': {}, #altitude
            'acc': {}, #acceleration
            'pres': {}, #pressure
            'temp': {}, #temperature
            'hum' : {}, #humidity
            'gyro': {}, #gyroscope
            'mag': {}, #magnetometric
            'uv': {}, #uv_index
            'air': {}, #air_quality
            'gps': {}, #gps_coordinates
            'bat': {} #battery_level
        }

        try:
            data['acc']['icm20948'] = self.accelerometer1.read_acceleration()
            data['mag']['icm20948'] = self.magnetometric1.read_magnetometer()
            data['gyro']['icm20948'] = self.accelerometer1.read_gyroscope()
            radiodata['acc']['icm20948'] = self.accelerometer1.read_acceleration_round()
            radiodata['mag']['icm20948'] = self.magnetometric1.read_magnetometer_round()
            radiodata['gyro']['icm20948'] = self.accelerometer1.read_gyroscope_round()
        except Exception as e:
            data['acc']['icm20948'] = None
            data['mag']['icm20948'] = None
            data['gyro']['icm20948'] = None
            radiodata['acc']['icm20948'] = None
            radiodata['mag']['icm20948'] = None
            radiodata['gyro']['icm20948'] = None
            self.log_error("acceleration/magnetometric/gyroscope", e)
#             log.log_entry("ERROR", "Error reading acceleration/magnetometric/gyroscope data", running="sensor_manager.py", function="collect_data()", error=f"{e}" )
#             print(f"Error reading acceleration/magnetometric/gyroscope data: {e}")

        try:
            data['temp']['bme688'] = self.pressure2.temperature
            data['pres']['bme688'] = self.pressure2.pressure
            data['hum']['bme688'] = self.pressure2.humidity
            data['alt']['bme688'] = self.pressure2.altitude
            radiodata['temp']['bme688'] = round(data['temp']['bme688'], 2)
            radiodata['pres']['bme688'] = round(data['pres']['bme688'], 2)
            radiodata['hum']['bme688'] = round(data['hum']['bme688'], 2)
            radiodata['alt']['bme688'] = round(data['alt']['bme688'], 2)
            #print(f"Temp: {self.pressure2.temperature}, Pres: {self.pressure2.pressure}, Hum: {self.pressure2.humidity}, Altitude: {self.pressure2.altitude}, Gas: {self.pressure2.gas}")
        except Exception as e:
            data['temp']['bme688'] = None
            data['pres']['bme688'] = None
            data['hum']['bme688'] = None
            data['alt']['bme688'] = None
            radiodata['temp']['bme688'] = None
            radiodata['pres']['bme688'] = None
            radiodata['hum']['bme688'] = None
            radiodata['alt']['bme688'] = None
            self.log_error("altitude", e)
#             log.log_entry("ERROR", "Error reading altitude", running="sensor_manager.py", function="collect_data()", error=f"{e}" )
#             print(f"Error reading altitude: {e}")

        try:
            data['temp']['lps25h'] = self.pressure1.read_temperature()
            data['pres']['lps25h'] = self.pressure1.read_pressure()
            data['alt']['lps25h'] = self.pressure1.read_altitude()
            radiodata['temp']['lps25h'] = round(data['temp']['lps25h'], 2)
            radiodata['pres']['lps25h'] = round(data['pres']['lps25h'], 2)
            radiodata['alt']['lps25h'] = round(data['alt']['lps25h'], 2)
        except Exception as e:
            data['temp']['lps25h'] = None
            data['pres']['lps25h'] = None
            data['alt']['lps25h'] = None
            radiodata['temp']['lps25h'] = None
            radiodata['pres']['lps25h'] = None
            radiodata['alt']['lps25h'] = None
            self.log_error("pressure/temperature", e)
#             log.log_entry("ERROR", "Error reading pressure/temperature", running="sensor_manager.py", function="collect_data()", error=f"{e}" )
#             print(f"Error reading pressure/temperature from LPS25H: {e}")
        
        try:
            data['temp']['mcp9808'] = self.temperature1.getTemp()
            radiodata['temp']['mcp9808'] = round(data['temp']['mcp9808'], 2)
        except Exception as e:
            data['temp']['mcp9808'] = None
            radiodata['temp']['mcp9808'] = None
            self.log_error("temperature", e)
#             log.log_entry("ERROR", "Error reading temperature from MCP9808", running="sensor_manager.py", function="collect_data()", error=f"{e}" )
#             print(f"Error reading temperature from MCP9808: {e}")
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

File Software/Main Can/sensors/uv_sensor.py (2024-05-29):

from machine import I2C, Pin
import time

class VEML6075:
    def __init__(self, i2c_channel=1, scl_pin=48, sda_pin=47, address = 0x10):
        self.i2c = I2C(i2c_channel, scl=Pin(scl_pin), sda=Pin(sda_pin))
        self.address = address
        self.channel = i2c_channel
        self.setup()

    def setup(self):
        # Initialize VEML6075
        self.i2c.writeto_mem(self.address, 0x00, bytearray([0x10]))  # Set UV configuration register
        # Enable the sensor (power on) and set active mode
        self.i2c.writeto_mem(self.address, 0x01, bytearray([0x06]))

    def read_uva(self):
        # Read UVA data
        data = self.i2c.readfrom_mem(self.address, 0x07, 2)
        uva = data[0] | data[1] << 8
        return uva

    def read_uvb(self):
        # Read UVB data
        data = self.i2c.readfrom_mem(self.address, 0x09, 2)
        uvb = data[0] | data[1] << 8
        return uvb

    def read_uv_index(self):
        # Calculate the UV Index using the UVA and UVB readings
        uva = self.read_uva()
        uvb = self.read_uvb()
        # Constants for UV Index calculation (may need calibration depending on environmental factors)
        uva_response = 1.0
        uvb_response = 1.0
        uv_index = (uva * uva_response + uvb * uvb_response) / 2.0
        return uv_index

# Example of initializing and reading from the sensor
# i2c_channel = 0
# scl_pin = 22
# sda_pin = 21
# sensor = VEML6075(i2c_channel, scl_pin, sda_pin)
# uva = sensor.read_uva()
# uvb = sensor.read_uvb()
# uv_index = sensor.read_uv_index()
# print("UVA:", uva, "UVB:", uvb, "UV Index:", uv_index)

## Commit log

2024-06-01 Added Temperature, Pressure and Altitude combo grapher
2026-04-15 fix: restore hyperendnotes.sty required by CDOSR_CanSat.sty
    CDOSR_CanSat.sty:23 \RequirePackage{hyperendnotes} — missed on the
    first pass because the usage is in a .sty, not a .tex file.
2026-04-15 fix(latex): repair legacy Overleaf source bugs
    Three pre-existing issues from the Overleaf import, all inherited:
    1. CDR CanSat_CDR_CDOSR.tex:84 — \caption and \label were outside
    the \end{table}, triggering "\caption outside float". Moved
    them inside the table float.
    2. PDR RCRC_PDR_CDOSR.tex — duplicate \end{document} (original at
    line 365, orphan at 367). LaTeX silently ignores the second one
    but it's dead code.
    3. CDR CanSat_CDR_CDOSR.tex — same duplicate pattern (lines 1597
    and 1599).
    Verified clean with a balance-check scanner across both src trees:
    no orphan begin/end envs, no captions outside floats.
2026-04-15 docs: rewrite Mission Docs README with PDR/CDR build instructions
    Rename readme.md -> README.md (case convention) and populate the
    previously-empty stub with:
    - Directory layout under Mission Docs/
    - pdflatex build commands for both documents
    - Notes on the EPS->PDF pre-conversion workaround, shared .sty
    duplication, and team roster inclusion
2026-04-15 docs: clarify split between Hardware/ and Documentation/Hardware/
    The team's CAD sources (Eagle .sch/.brd) live at the repo root under
    Hardware/PCB Designs/, while third-party component datasheets live
    under Documentation/Hardware/Data Sheets/. Keep them where they are
    and cross-reference so anyone browsing either tree knows the other
    half exists.
    - Hardware/readme.md: drop references to the nonexistent Schematics/
    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
2026-04-15 Add EAGLE PCB sources for 4 custom 2024 boards
    Schematic and board layout files for the four boards designed for
    CanSat 2024:
    - Comm_board_2024_L76 (Quectel L76 GNSS)
    - Comm_board_2024_M8N (u-blox NEO-M8N GNSS)
    - Power_board_2024
    - Sensor_board_2024
    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
    [Comm_board_2024_L76.brd, Comm_board_2024_L76.sch, Comm_board_2024_M8N.brd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]

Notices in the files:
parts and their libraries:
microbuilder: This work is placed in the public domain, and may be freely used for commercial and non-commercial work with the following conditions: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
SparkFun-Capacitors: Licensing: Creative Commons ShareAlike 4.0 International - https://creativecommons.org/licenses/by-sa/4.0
